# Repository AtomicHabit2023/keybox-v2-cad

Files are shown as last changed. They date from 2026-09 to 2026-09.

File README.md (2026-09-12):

# KeyBox V2 CAD

Shared design workspace for the 48-door KeyBox V2 mechanical/CAD project.

## Working model

- **ChatGPT**: project designer / design authority. Maintains requirements, parameters, design decisions, review gates, corrections, and approvals.
- **Codex**: CAD execution agent. Uses Fusion 360 through MCP to build, measure, test, and report the actual model.
- **Fusion 360**: authoritative geometric/interference environment.
- **GitHub**: shared source of truth and agent-to-agent handoff channel.
- **Owner**: product/business owner and physical-world operator; should not be used as a routine message courier between ChatGPT and Codex.

## Read these first

1. `AGENTS.md`
2. `CAD_REVIEW_PROTOCOL.md`
3. latest applicable files under `reviews/`
4. `CAD_MASTER_SPEC.md`
5. `PARAMETERS.json`
6. `DESIGN_DECISIONS.md`
7. `CAD_TASKS.md`
8. `CAD_LOG.md`

## Direct agent workflow

From CAD-002 onward, Codex works on one task branch such as `cad/CAD-002`, saves Fusion evidence, writes `handoff/CAD-002.json`, commits and pushes through the restricted **KeyBox Git Bridge MCP**, and stops at the review gate.

ChatGPT reviews the pushed branch/PR and returns one of `APPROVED`, `CHANGES_REQUIRED`, or `HUMAN_DECISION_REQUIRED` in `reviews/CAD-###_RESULT.md`.

The owner is asked only when a physical measurement, fabrication-shop fact, purchase/cost fact, installation constraint, or product/business tradeoff genuinely requires a human decision.

See `CAD_REVIEW_PROTOCOL.md` for the full contract.

## KeyBox Git Bridge MCP

`tools/keybox_git_bridge/` contains a restricted local MCP server for Git fetch/pull/branch/stage/commit/push operations. It runs in the normal Windows user context so Git can use the owner's existing SSH setup, while Codex never receives direct access to the private SSH key. Direct pushes to `main` are blocked by the bridge.

## Current CAD status

- Phase-1 parameter/reference geometry was successfully created in Fusion 360.
- The earlier Phase-2 master latch reference was geometrically inaccurate and is **superseded**.
- CAD-001 has been restored to the correct baseline: maximum complete formed door envelope `87.5 × 47.0 mm`; the planar center face is derived (restored baseline about `84.8 × 41.6 mm`).
- CAD-002 remains blocked until CAD-001's final evidence checkpoint is explicitly approved.

## Manufacturing philosophy

Design for ordinary Thai laser-cut / press-brake / welding shops, not specialized tooling. Keep the product parametric, self-jigging, low-part-count, serviceable, and inexpensive to fabricate. Critical repeated dimensions must come from named parameters, never duplicated hard-coded values.

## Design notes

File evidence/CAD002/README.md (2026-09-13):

# CAD-002 corrected U-catch review evidence

Status: READY_FOR_DESIGN_REVIEW

Controlling decision: reviews/CAD-002_RESULT.md, read from refreshed main at 1070e73 on 2026-09-13. This evidence supersedes the original CAD-002 package and its provisional spacing.

## Corrections and verification

- Plate: 20.0 x 34.5 x 1.5 mm; local X 62.5-82.5, Y 12.0-13.5, Z 7.75-42.25 mm.
- Two through-holes in the catch plate only: diameter 4.2 mm, vertical centers 25.0 mm apart (drawing tolerance +/-0.2 mm). Centers X 72.5, Z 12.5 and 37.5 mm. The approved door return was not drilled or modified.
- Two diameter 3.0 mm projecting legs: centers X 65.5 and 79.5 mm, both at Z 25.0 mm; axes parallel to Y. Horizontal center spacing 14.0 mm, outside width 17.0 mm, inside clear spacing 11.0 mm.
- Projection: 26.0 mm from plate outer face Y 13.5 to loop furthest Y 39.5 mm (drawing tolerance +/-1 mm).
- Original edge inset remains 5.0 mm from door-edge reference X 87.5 to plate edge X 82.5 mm.
- Catch occurrence transform matches the door at the original 550 mm X review offset and is grounded for static review.
- Rebuilt only the catch using six fully constrained sketches and six healthy extrusion/cut features. Functional dimensions and offsets reference named parameters.
- Door body revision is identical before and after correction: 947b7e2e-ea4f-4ad2-9d0f-8d0c880a28ae. Volume, 46 faces, 100 edges, one sheet-metal body, 10 healthy features, 87.5 x 12 x 47 mm bounds, and existing flat pattern are preserved.
- The four-body purchased-hardware reference retains simple cylindrical legs and distal bridge. Cosmetic welds and detailed bend-end refinements are outside this correction.

## Evidence

- CAD002_front.png: plate front view from the compartment side (+Y looking toward -Y), with Z vertical; shows horizontal loop orientation and both mounting holes.
- CAD002_top.png: view from +Z, showing loop projection and width.
- CAD002_isometric.png: assembled view from the compartment side.
- CAD002_MEASUREMENTS.json: fresh Fusion geometry measurements and acceptance assertions; all pass.
- KeyBox_V2_CAD002_UCatch.f3d: corrected native Fusion checkpoint.

The three images were visually inspected after export. The saved Fusion document is KeyBox_V2_CAD002_UCatch.

No provisional loop-spacing deviation remains. This is the static CAD-002 gate only. No shield, lock body, red wall, shim, hinge rod, motion study, or pattern was added. CAD-003 remains blocked pending design-authority approval.

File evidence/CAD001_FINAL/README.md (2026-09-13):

# CAD-001 Final Baseline Evidence

This package records the restored, correct CAD-001 master-door baseline for final design review.

## Controlling interpretation

- The complete formed door envelope is **87.5 x 12.0 x 47.0 mm**.
- The uninterrupted planar front region is a derived result of approximately **84.8 x 41.6 mm**.
- The formed envelope fits the **90 x 50 mm** cell pitch with nominal gaps of 2.5 mm horizontally and 3.0 mm vertically.
- All four 90-degree bends are healthy and point in the required inward/hidden-return directions.
- The sheet-metal body and flat pattern are healthy.

## Files

- `CAD001_FINAL_front.png` - front review view of the restored baseline.
- `CAD001_FINAL_top.png` - top review view of the restored baseline.
- `CAD001_FINAL_isometric.png` - isometric review view of the restored baseline.
- `CAD001_FINAL_MEASUREMENTS.json` - machine-readable geometry, feature-health, fit, and scope checks.
- `KeyBox_V2_CAD001_MasterDoor_FINAL.f3d` - saved native Fusion checkpoint of the restored baseline.

## Provenance and scope

The images, measurements, and native checkpoint are taken from the saved original CAD-001 baseline that predates and supersedes the abandoned oversized CAD-001R attempt. No CAD-001R artifact is included in this package. No Fusion geometry was modified while preparing this final review package, and CAD-002 was not started.

This checkpoint is for design review only and is not a released manufacturing blank.

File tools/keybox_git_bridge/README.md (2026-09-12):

# KeyBox Git Bridge MCP

A deliberately restricted local MCP server that lets Codex perform the Git operations needed for the KeyBox V2 CAD review loop **without giving the Codex sandbox direct access to the owner's SSH private key or unrestricted filesystem**.

The bridge runs as the normal Windows user, listens only on localhost, is hard-scoped to one repository, and exposes only a small allowlist of Git operations.

## Allowed repository

Default:

`C:\Users\wirat\Documents\Codex\keybox-v2-cad`

Override only when deliberately relocating the repo:

`KEYBOX_REPO=<absolute path>`

Default MCP endpoint:

`http://127.0.0.1:8765/mcp`

## Exposed tools

- `git_status`
- `git_log`
- `git_diff_summary`
- `git_fetch_origin`
- `git_pull_ff_only`
- `git_create_or_switch_branch`
- `git_stage`
- `git_commit`
- `git_push_head`

Safety behavior:

- no arbitrary shell command tool;
- no delete/reset/clean/rebase/force-push tool;
- `git_stage` accepts only explicit repository-relative paths;
- branch names are validated;
- `git_push_head` refuses to push `main`;
- subprocesses use `shell=False`;
- all commands run only inside the configured KeyBox repository;
- HTTP transport binds to `127.0.0.1`, not the LAN.

## One-time install

Python 3.10+ is required. The official MCP Python SDK v2 is used.

Run from a **normal Windows PowerShell**, not inside the Codex sandbox:

```powershell
cd C:\Users\wirat\Documents\Codex\keybox-v2-cad\tools\keybox_git_bridge
py -m venv .venv
.\.venv\Scripts\Activate.ps1
python -m pip install --upgrade pip
python -m pip install "mcp>=2,<3"
```

## Start the bridge

From the same normal Windows account:

```powershell
cd C:\Users\wirat\Documents\Codex\keybox-v2-cad\tools\keybox_git_bridge
.\.venv\Scripts\Activate.ps1
python server.py
```

Leave that small PowerShell window running while Codex is doing CAD work. The bridge should listen at:

`http://127.0.0.1:8765/mcp`

The server code uses MCP Streamable HTTP. The official MCP Python SDK v2 supports this transport; the server is intentionally local-only.

## Add to Codex

Add a custom HTTP MCP server named something like:

`keybox-git`

with URL:

`http://127.0.0.1:8765/mcp`

Exact UI placement can vary by Codex version. After adding it, ask Codex to list/use the `keybox-git` tools.

## First connection test

Ask Codex to call only:

`git_status`

Expected result: it reports the KeyBox repository path, current branch and status **without trying to read `.ssh` from inside the Codex sandbox**.

Then test:

1. `git_fetch_origin`
2. `git_status`

For real CAD work, create branches only when a task is released, e.g. `git_create_or_switch_branch("cad/CAD-002")`.

## Why this solves the earlier failure

Codex's normal sandbox could edit the repository but could not read the user's `C:\Users\wirat\.ssh` credential files. This bridge runs in the normal Windows user context, so Git can use the already-configured SSH/ssh-agent environment while Codex sees only narrow Git tools, never the private key itself.

## Operational rule

From CAD-002 onward Codex should use the bridge for all network Git operations and work on `cad/CAD-###` branches. Direct pushes to `main` remain blocked by the bridge.

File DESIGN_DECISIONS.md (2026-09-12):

# Design Decisions — KeyBox V2

This file records the **current approved decisions** and important superseded ideas so CAD execution does not regress to earlier concepts.

## Current approved decisions

- 48 compartments = 4 columns × 12 rows.
- Horizontal order: Col1 + SVC1 + Col2 + Col3 + SVC2 + Col4.
- 90 mm column pitch, 50 mm row pitch, 100 mm compartment depth, 40 mm service channel clear width.
- Structural sheet: 1.2 mm nominal **hot-rolled** mild steel.
- Starting slot width for tab/grid interlock: 1.30 mm = 1.20 + 0.10 mm allowance.
- Col2/Col3 use 50/50 mm half-depth egg-crate interlock through 100 mm depth.
- Col1/Col4 use separate outer-divider family.
- Shared full-height Ø4 mm hinge rod per column; 4 rods total.
- Door uses 10 mm top and bottom inward flanges with rod holes.
- Door face starting size: 87.5 × 47.0 mm.
- Latch side uses double 90° folds: 12 mm first flange + 25 mm return flange.
- U-catch is moved 5 mm inward from original door-edge reference.
- Catch sweep must be checked dynamically; V1 failed from swept-path collision.
- Blue protective shield is integrated into continuous formed sheet geometry and must have local U-catch pass-through relief/opening.
- Red service wall stops near lock rear; it is not full 100 mm deep.
- XG-07A lock requires one-piece shim between lock body and red wall.
- Prototype lock mounting: 1 round locating hole + 2 short adjustment slots.
- Two harness routes per 40 mm service channel, center kept clear.
- Control-bay UI layout: **Display → Keypad → QR**, horizontal.
- Control bay rear cover: bottom-hinged swing-down service panel; low-voltage controller electronics can mount to it.
- Moving cabinet rear structural frame: 25×25×3 mm angle iron.
- Main cabinet service opening: **90° to the left**, not 180°.
- Wall support architecture: fixed left hinge rail + bottom support rail + right support structure.
- Two Solex master locks on right side: upper-right and lower-right, preferably keyed alike.
- Bottom wall rail carries closed-position weight; master locks provide security, not primary structural support.
- Powder coat only after complete bare-steel functional dry-build passes.

## Superseded / rejected ideas

- 64-box target for this V2 cabinet — current cabinet design is 48 boxes.
- 6×8 layout — replaced by 4×12.
- Individual concealed pivot pins per door — rejected; returned to shared full-height rods.
- Separate bolt-on solenoid shield — superseded by integrated formed shield concept.
- Full-depth red service wall — rejected because it blocks rear wiring/service access.
- Full-depth blue shield to the front — rejected because it conflicts with double-fold/U-catch sweep.
- Whole service-wall front setback — rejected due security/open-gap concern.
- Four removable concrete-wall bolts as normal cabinet closure — rejected; fixed support rails restored.
- Custom vertical two-point master-lock linkage — rejected in favor of two simple Solex locks.
- 180° cabinet service swing — rejected because hinge offset becomes awkward; current requirement is 90°.
- Vertical UI stack — replaced by horizontal Display-Keypad-QR layout.
- Cold-rolled SPCC requirement — replaced by commonly available 1.2 mm hot-rolled mild steel.
- 1.4–1.5 mm tab-slot width — replaced by 1.30 mm starting slot width based on user V1 fabrication experience.
- Earlier Phase-2 Fusion master-latch reference geometry — geometrically inaccurate and must not be reused as the basis for final CAD.

## Process decision

ChatGPT remains design authority. Codex is CAD execution agent through Fusion MCP. Codex must not silently invent mechanical decisions. Every high-risk feature is built and reviewed incrementally before replication.

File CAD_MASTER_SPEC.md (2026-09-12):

# CAD Master Specification — KeyBox V2

## 1. Product goal

48-door smart apartment key cabinet intended for complete installed supply in Thailand. V2 must prove both functional reliability and local fabrication economics. The metal cabinet design is intended to be manufacturable by ordinary Thai laser-cut / press-brake / welding shops, while electronics/software remain the differentiated smart-control layer.

## 2. Frozen overall architecture

- Capacity: **48 key compartments**.
- Arrangement: **4 columns × 12 rows**.
- Horizontal sequence, left to right:
  **Col1 + Service #1 + Col2 + Col3 + Service #2 + Col4**.
- Nominal locker column pitch: **90 mm**.
- Nominal row pitch: **50 mm**.
- Compartment nominal depth: **100 mm**.
- Service-channel clear width: **40 mm** each.
- Locker matrix height: **600 mm**.
- Core internal width: **440 mm** before outer skins / finished edge geometry.
- Structural sheet: **1.2 mm nominal hot-rolled mild steel**.

Each apartment stores one normal key on a small ring/tag; usable key-space width may therefore be significantly less than 90 mm after lock/shield allocation.

## 3. Service-channel / lock architecture

Each service channel serves 24 locks: 12 from each adjacent column.

- XG-07A style 4-wire electronic locker lock.
- Lock body is inside each tenant compartment, adjacent to service channel.
- Lock is protected from tenant access by a formed shield integrated into the sheet geometry.
- Solenoid mounting screws are accessed from the protected service side.
- Lock wires exit into service channel and run upward to control bay.
- Rear access must permit replacing the lock without removing the door, horizontal divider, blue shield, or neighboring lock.
- Red service wall depth is **not 100 mm**; it stops near the rear edge of the solenoid to leave an open wire/service zone.
- Blue shield must have a laser-cut U-catch pass-through opening sized from the actual U-catch swept envelope plus clearance.

## 4. Master door geometry

Starting values:

- Visible door face width: **87.5 mm**.
- Visible door face height: **47.0 mm**.
- Door sheet: **1.2 mm**.
- Top inward hinge flange: **10 mm**.
- Bottom inward hinge flange: **10 mm**.
- Shared hinge rod: **Ø4 mm stainless steel**.
- Door hinge holes: **Ø4.6 mm starting**.
- Nylon/PTFE washer: **0.5 mm starting**.

The top and bottom flanges contain the hinge holes; one full-height rod serves all 12 doors in a column. Four columns = four shared rods.

### Latch-side folds

- First latch-side flange: **12 mm**, 90°.
- Second return flange: **25 mm**, 90°.
- U-catch plate width: **20 mm**.
- Catch is positioned **5 mm inward from the original door-edge reference**, so the 25 mm return is conceptually 20 mm catch plate + 5 mm inset.
- Final catch placement must be checked against the physical XG-07A catch and hook.

### Critical V1 lesson

The V1 cabinet failed because the U-catch could fit at the final closed position but collided with the wall during its rotating sweep. V2 must always be designed from the **full moving swept envelope**, not only open/closed static positions.

Minimum starting sweep clearance: **4 mm** around the real moving U-catch geometry where required.

## 5. Blue shield and red wall

The user-approved cross-section uses continuous formed sheet geometry, with a protected lock zone adjacent to the service channel.

- Starting clear key-space width: **65 mm**.
- Starting lock/shield zone width: **25 mm**.
- Blue protective shield is continuous vertically for a column where practical.
- Blue shield begins only behind the latch sweep zone; its exact front setback is CAD-derived from the actual catch sweep.
- Blue shield requires a local laser-cut pass-through for the U-catch.
- Red service wall is continuous where required to mount locks but stops at/near the rear of the lock, leaving rear service access into the 40 mm channel.
- No straight unauthorized tool path from tenant compartment into lock wiring/emergency-release area.

## 6. XG-07A / shim / mounting

Nominal XG-07A reference dimensions from supplied drawing:

- Body length: ~53 mm.
- Body height: ~40 mm.
- Body thickness: ~13 mm.
- Catch plate: ~20 mm × 36.5 mm.
- Catch loop projection: ~26 mm.
- Three M4 mounting holes in lock body.
- Emergency manual release and wiring are at the rear end.

A **rigid one-piece shim** is mandatory between lock body and red service wall. It accounts for catch inset plus additional alignment offset. Starting shim expectation is approximately **7–8 mm**, but final thickness must be derived from actual hook-to-catch alignment in CAD and prototype testing.

Prototype-friendly mounting pattern on red service wall:

- **1 locating round hole**.
- **2 short adjustment slots**.
- Starting round-hole diameter: **4.5 mm**.
- Starting slot width: **4.5 mm**.
- Starting slot length: **7.0 mm**.

The nominal mounting pattern must be derived from the final hook/catch geometry. Codex must not assume a guessed pattern is fabrication-ready.

## 7. Horizontal dividers / grid

Two divider families are required:

1. **Outer divider** for Col1 and Col4.
2. **Center divider** spanning Col2 + Col3.

Col2/Col3 use a true egg-crate interlock:

- Compartment depth: 100 mm.
- Horizontal divider slot: **50 mm deep** from one edge.
- Central vertical divider slot: **50 mm deep** from the opposite edge.
- Starting nominal slot width: **1.30 mm** for 1.2 mm nominal sheet.

The horizontal tenant divider stops at the blue shield and does not unnecessarily divide the vertical lock/service strip.

There are 11 internal row dividers; top and bottom structural plates provide the remaining boundaries.

## 8. Tab / slot rules

- `SHEET_T = 1.20 mm` nominal.
- `SLOT_CLEARANCE = 0.10 mm` starting.
- `SLOT_W = SHEET_T + SLOT_CLEARANCE = 1.30 mm` starting.
- All repeated slots must reference one named parameter.
- Laser-cut slots/tabs establish geometry and squareness.
- Welding only locks an already-located structure; welding must not establish pitch or alignment.
- Avoid long continuous welds on 1.2 mm sheet to reduce distortion.

## 9. Door rod support

- Four full-height Ø4 mm stainless rods.
- Rods pass through door top/bottom flange holes.
- Bottom matrix plate guides rod but should not be the sole axial support.
- Add a dedicated bottom-front hinge support rail beneath the matrix; rod projects through plate and rests/supports at the lower rail.
- Rods withdraw upward into top control bay for rare door replacement.
- Top control bay contains removable rod-retention/keeper feature.

## 10. Control compartment

- Control bay width = exact finished cabinet-body width.
- Nominal depth: **100 mm**.
- Starting height: **~165 mm**, adjust from actual UI packing.
- Horizontal front layout, left to right:
  **Display → Keypad → QR**.
- Keypad should be biased closer to display than QR because display+keypad form one workflow.
- Fixed secure front fascia; no public-side service fasteners.
- One removable internal UI carrier plate for display/keypad/QR.
- Rear service panel is bottom-hinged and swings down after the whole cabinet is opened.
- Rear panel retained at top by two repeated-service machine screws into captive/rivnut-type threads.
- Support straps keep rear service panel near ~90° open position.
- Low-voltage controller electronics may mount on the swing-down rear service panel.
- Prefer fixed mains/high-voltage and heavier PSU items in main enclosure rather than repeatedly flexing mains wires on service tray.

Reference UI hardware:

- 3.5 in ILI9488 display, non-touch preferred.
- Industrial keypad ~79.5 × 99.5 mm face.
- GM865 QR scanner.

## 11. Vertical-service-channel wiring

Each 40 mm channel has two harness routes, one along each side, leaving the center clear for tools/emergency access.

- Keep factory lock pigtail replaceable via connector.
- Place connector toward the rear open service portion, away from U-catch/hook motion.
- Starting lock service loop: **60 mm**.
- Use small laser-cut cable-tie slots rather than bulky cable duct where practical.
- Assume all four XG-07A conductors remain available until electrical bench testing proves otherwise.

## 12. Rear structural frame / wall mounting

Moving cabinet:

- Full rear perimeter frame: **25 × 25 × 3 mm angle iron**.
- Three substantial hinges on left side.
- Cabinet service swing: **90°**, left-opening.
- Hinge axis may therefore sit close to rear wall plane; exact hardware clearance still CAD-derived.

Fixed wall support:

- Left hinge rail.
- Bottom support rail carrying closed-position weight.
- Right support rail / upper support structure for alignment and security.

The cabinet should not rely on hinge cantilever load during normal closed operation.

## 13. Master service locks

Use **two Solex padlocks / master-key locks**, preferably keyed alike:

- Lower-right.
- Upper-right.

Each locks the moving 25×25×3 structural frame to the corresponding fixed support structure via aligned holes. Bottom support continues to carry cabinet weight; locks provide security, not primary structure.

Master-lock hole diameter and offsets remain hardware-derived parameters.

## 14. Materials and finish

- Main structural sheet: **1.2 mm nominal hot-rolled mild steel**.
- Main rear moving frame: **25×25×3 mm mild-steel angle**.
- Shared door hinge rods: **Ø4 mm SUS304 stainless starting choice**.
- Powder coat after all welding and bare-steel functional dry-build checks.
- Starting powder thickness target: roughly **70–90 μm**.
- Proper preparation needed for hot-rolled surface / scale / oil before coating.
- Repeated-service fasteners: machine screws into captive nuts/rivnuts; avoid self-tapping screws for repeated maintenance points.

## 15. Sheet-metal modeling rules

Global starting parameters:

- Inside bend radius: **1.5 mm**.
- K-factor: **0.42** starting only; calibrate with actual shop/bend coupon.
- Standard bend: 90° unless specified.
- Bend-relief starting width: 2.0 mm.
- Bend-relief starting depth: 3.5 mm.

Critical dimensions describe the **finished folded geometry**. Flat patterns should derive from the Fusion sheet-metal rule rather than hard-coded manual deductions.

The U-catch sweep relief is a separate functional feature and must not be conflated with generic bend relief.

## 16. Assembly / prototype sequence

1. Build locker grid in bare steel using tab/slot geometry.
2. Add control shell and rear structural frame.
3. Prove shared hinge rods fit and withdraw correctly before doors.
4. Build and prove **one master door/latch cell**.
5. Only after the master cell passes, replicate to all 48 positions.
6. Fit all doors/locks in bare steel and cycle them.
7. Fit wall-support system, 90° cabinet swing, and two right-side master locks.
8. Fit rear controller tray and front UI carrier.
9. Mock up wiring and confirm every lock remains rear-serviceable.
10. Only after all functional checks: final welds, re-check, disassemble removable hardware, powder coat, final assembly.

## 17. Master-cell acceptance gates

Before replication, the one-row master cell must prove all of the following:

- Door rotates without interference.
- 12 mm + 25 mm folds are oriented exactly as intended.
- U-catch is represented from real dimensions, not a crude bounding block.
- U-catch passes through shield opening throughout motion.
- No collision with blue shield/service-side wall through full door sweep.
- U-catch engages XG-07A hook positively.
- Shim thickness gives correct hook/catch relationship.
- 1 round + 2 slot lock mounting system provides controlled prototype adjustment.
- Emergency release remains accessible from service side.
- Lock and shim can be removed/reinstalled from rear without removing door/divider/shield/neighbouring lock.
- Tenant cannot directly access lock mounting screws, wiring, or emergency release.

## 18. CAD governance

- All repeated dimensions are named user parameters.
- Do not hard-code the same functional dimension in multiple sketches/features.
- Do not pattern 48 copies until the master cell is explicitly approved.
- Do not fabricate from provisional reference solids.
- Do not silently resolve contradictions. Stop and document them for design review.
- Maintain a running execution log in `CAD_LOG.md`.

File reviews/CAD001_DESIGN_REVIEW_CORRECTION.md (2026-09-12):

# CAD-001 Design Review Correction — Envelope vs planar face

## Status
The previous review instruction that required an uninterrupted planar front face of **87.5 × 47.0 mm** is **rescinded**.

## Reason
CAD-001R demonstrated that keeping the planar face at 87.5 × 47.0 mm produces a formed overall envelope of about **90.2 × 52.4 mm**. That exceeds the 90 × 50 mm cell pitch and therefore violates the required inter-door clearance.

The original CAD-001 interpretation was physically correct for the cabinet layout:

- **DOOR_ENVELOPE_W = 87.5 mm**
- **DOOR_ENVELOPE_H = 47.0 mm**

These are the maximum formed front-projection dimensions of the complete bent door, not the uninterrupted planar center panel.

With R1.5 mm and 1.2 mm sheet, the corresponding uninterrupted planar region was measured at about **84.8 × 41.6 mm**. That is acceptable; it is a derived consequence of the bend radii and is not itself the controlling cabinet-fit dimension.

## Required action
1. Stop CAD-001R before committing it as an approved replacement.
2. Restore/retain the original CAD-001 formed-envelope geometry where the complete door fits within 87.5 × 47.0 mm.
3. Keep the 10 mm top/bottom inward hinge flanges, 12 mm first latch flange, 25 mm return, R1.5 mm, K=0.42 starting rule, and the existing healthy sheet-metal topology.
4. Treat the planar front-panel size as a **derived** value, not a fixed requirement.
5. Do not start CAD-002 until this correction is acknowledged and the CAD-001 checkpoint is confirmed as the active baseline.

## Parameter naming correction
To avoid recurrence, use these meanings going forward:

- `DOOR_ENVELOPE_W = 87.5 mm`
- `DOOR_ENVELOPE_H = 47.0 mm`
- `DOOR_PLANAR_W = derived`
- `DOOR_PLANAR_H = derived`

The controlling requirement for cabinet fit is the **formed overall envelope** because the 90 × 50 mm cell pitch must retain the intended nominal gaps.

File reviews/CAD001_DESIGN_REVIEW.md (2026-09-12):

# CAD-001 Design Review

**Review status:** CHANGES REQUIRED  
**Design authority:** ChatGPT / project-design conversation  
**Reviewed checkpoint:** `93bb356aac7aac63e48f8a53af0fcd691be8e168`  
**CAD-002:** BLOCKED until CAD-001R is re-reviewed and approved.

## What is accepted from the checkpoint

The following parts of CAD-001 are accepted as the correct direction and should be preserved unless the required correction forces a rebuild:

- one true Fusion sheet-metal body;
- 1.2 mm hot-rolled-steel design thickness;
- starting sheet-metal rule R1.5 mm / K-factor 0.42;
- 10 mm top inward hinge flange;
- 10 mm bottom inward hinge flange;
- 12 mm first latch-side inward flange;
- 25 mm second latch-side return;
- all four bends at 90 degrees and directed inward toward the tenant compartment;
- current corner relief is acceptable as a prototype starting point, subject to later fabrication calibration;
- flat pattern generation is healthy;
- no U-catch, shield, lock, shim, hinge rod, or 48-copy pattern was added before the stop gate.

## Required correction

The checkpoint interpreted `DOOR_FACE_W = 87.5 mm` and `DOOR_FACE_H = 47.0 mm` as the **complete formed front projection including bend zones**. That is not the approved design intent.

**Approved definition:**

`DOOR_FACE_W = 87.5 mm` and `DOOR_FACE_H = 47.0 mm` are the dimensions of the **flat planar visible front face between the bend tangency/bend-start lines**.

The current checkpoint reports the largest uninterrupted planar front region as only **84.8 × 41.6 mm**, so CAD-001 does not yet satisfy the approved door-face requirement.

## CAD-001R instruction

Revise only the master door/folds geometry so that:

1. the planar visible front face measures **87.5 mm wide × 47.0 mm high** between the bend-start/tangency boundaries;
2. the 10 mm top and bottom flanges remain inward;
3. the 12 mm first latch flange remains inward;
4. the 25 mm second return remains the hidden return that will later carry the U-catch;
5. the body remains valid sheet metal and still produces a valid flat pattern;
6. no bend or relief self-intersects;
7. after correcting the planar face, measure the **actual formed overall envelope** and report it separately;
8. compare that formed envelope against the **90 mm × 50 mm cell pitch**. If any formed portion would interfere with the neighboring row/column or violate the intended door gaps, **STOP and report the conflict; do not change the approved 87.5 × 47.0 planar-face dimensions without design-authority approval**;
9. do not add U-catch, blue shield, red wall, XG-07A, shim, hinge rod, or any patterned copies.

## Dimension terminology to use from now on

- **Door face:** flat planar front face between bend tangencies; target 87.5 × 47.0 mm.
- **Formed envelope:** maximum outside bounds of the complete folded door; this is a reported/check dimension, not the definition of `DOOR_FACE_W/H`.
- **Cell pitch:** 90 × 50 mm structural pitch; formed envelope must be checked against it.

## Review gate for CAD-001R

Return for review with:

- front / top / isometric screenshots;
- exact planar-face measurement;
- exact formed-envelope measurement;
- sheet-metal feature health;
- flat-pattern health;
- explicit clearance/interference statement relative to the 90 × 50 mm cell pitch;
- updated `.f3d` checkpoint and machine-readable measurement file.

Do **not** start CAD-002 until this review file is superseded by an explicit `CAD-001 APPROVED` decision.

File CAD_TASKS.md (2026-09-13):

# CAD Tasks — KeyBox V2

## CAD-001 — Rebuild master door cell, folds only

**Status:** APPROVED

### Approved baseline

- Reference cell: 90 × 50 × 100 mm.
- Complete formed door envelope: **87.5 × 12.0 × 47.0 mm**.
- Derived uninterrupted planar front region: approximately **84.8 × 41.6 mm**.
- Door sheet: 1.2 mm.
- Top inward hinge flange: 10 mm.
- Bottom inward hinge flange: 10 mm.
- First latch-side flange: 12 mm at 90°.
- Second latch-side return flange: 25 mm at 90°.
- Starting sheet-metal rule: 1.2 mm thickness, 1.5 mm inside bend radius, K-factor 0.42.
- Four required bends healthy; flat pattern healthy.

`87.5 × 47.0 mm` remains the **maximum complete formed door envelope**, not the uninterrupted planar center face.

See `reviews/CAD-001_RESULT.md` for the controlling approval.

---

## CAD-002 — Real U-catch on approved door

**Status:** APPROVED

### Approved geometry

- Preserve the approved CAD-001 sheet-metal door unchanged.
- Catch plate: **20.0 × 34.5 × 1.5 mm**.
- Two catch mounting holes: **Ø4.2 mm**, **25.0 ±0.2 mm** vertical center-to-center.
- U-loop rod diameter: **3.0 mm**.
- Two projecting U-loop legs arranged **horizontally left-right in plate front view**.
- Owner-measured rod outside-to-outside width: **17.0 mm**, giving **14.0 mm center-to-center** and **11.0 mm inside clear spacing**.
- Catch loop projection: **26 ±1 mm** from the plate.
- Catch mounted on the 25 mm hidden return with the approved **5.0 mm inward edge inset**.
- Approved door remains unchanged and healthy.

See `reviews/CAD-002_RESULT.md` for the controlling approval.

---

## CAD-003 — Blue shield + true U-catch sweep

**Status:** CHANGES REQUIRED / L-SHIELD REBUILD RELEASED — see `reviews/CAD-003_RESULT.md` and `DESIGN_ERRATA.md` E-002

### Frozen hinge axis

- `HINGE_AXIS_EDGE_OFFSET = 5.0 mm` from the hinge-side door edge.
- `HINGE_AXIS_FRONT_OFFSET = 5.0 mm` behind the front-face plane.
- Axis direction = Z.
- Ø4.6 mm door guide holes centered on this axis for the Ø4.0 mm shared hinge rod reference.

### Controlling shield form

- Tenant key-space width: **65 mm**.
- Lock/shield-zone width: **25 mm**.
- Blue shield is a formed **L-section**, not a small frame.
- Side partition: constant-X Y-Z sheet at nominal **X = 65 mm**, running rearward from a CAD-derived front setback toward the compartment rear.
- Front return: short constant-Y X-Z face at the side partition's leading edge, turning toward the service-channel side across the **25 mm lock zone**.
- U-catch passage: local **horizontal slot/notch in the front return**, sized from the real moving U-catch envelope plus at least **4 mm** clearance.
- `BLUE_SHIELD_FRONT_SETBACK` is the Y position of the front return / leading bend.
- The side partition remains continuous/solid except for only minimum proven transition relief.
- Do **not** use the rejected four-web rectangular frame or the superseded full-width constant-Y wall / 119 mm relief.

### Corrected scope

- Preserve approved CAD-001 door and CAD-002 U-catch unchanged.
- Keep the frozen 5 mm / 5 mm hinge axis.
- Rebuild the CAD-003 shield reference as one lightweight 1.2 mm L-shaped formed sheet segment for the master row:
  - side leg at X=65 mm;
  - side leg extends from `BLUE_SHIELD_FRONT_SETBACK` rearward toward Y=100 mm;
  - front return at the leading edge spans nominally X=65..90 mm.
- Model the U-catch slot/notch in the front return, not as a freestanding frame around the catch.
- Evaluate motion at 0°, 15°, 30°, 45°, 60°, 75°, and 90°.
- Derive both the front setback and the smallest practical front-return slot/notch from the moving catch envelope.
- Measure clearance to slot/notch edges and any nearby side-partition/bend metal.
- Minimum required moving clearance = **4.0 mm**; review target >=4.5 mm where practical.
- Keep maximum protective metal and avoid a straight tenant tool path toward wiring/emergency-release areas.

### Do not build yet

- XG-07A lock body.
- Shim.
- Red service wall.
- Final/full hinge hardware beyond the lightweight axis/reference needed for the corrected motion study.
- Patterned rows or columns.

### Stop gate / evidence

Correct only CAD-003. Save a new Fusion checkpoint; provide an isolated clear view of the full L-shaped shield segment plus front/top/isometric and 0°/15°/30°/45°/60°/75°/90° motion evidence; report front setback, front-return span, slot/notch X/Z extents, governing edge/corner, closest angle, and minimum clearance; update `CAD_LOG.md`; update `handoff/CAD-003.json` with `READY_FOR_DESIGN_REVIEW`; push branch `cad/CAD-003`; stop for design-authority review.

---

## CAD-004 — XG-07A + shim + red wall

**Status:** BLOCKED

Planned scope: build actual lock reference from drawing/measurements, derive shim thickness from hook/catch alignment, add red wall, and implement 1 round locating hole + 2 short adjustment slots.

---

## CAD-005 — Master-cell serviceability validation

**Status:** BLOCKED

Planned scope: prove rear removal/reinstallation of lock+shim, emergency-release access, wiring clearance, tenant anti-tamper separation, and zero motion interference.

---

## CAD-006 — Replicate to grid and structural architecture

**Status:** BLOCKED until master cell approved

Planned scope: only after CAD-001 through CAD-005 pass, pattern approved geometry into 4×12 structure, create outer/center divider families, service channels, shared rods, control bay, rear structural frame, wall supports, and master-lock geometry.

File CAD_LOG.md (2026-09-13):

# CAD Execution / Review Log — KeyBox V2

## 2026-09-12 — Workspace initialized

- GitHub repository established as shared design/CAD handoff channel.
- ChatGPT designated project designer / design authority.
- Codex designated CAD execution agent through Fusion MCP.
- Fusion 360 remains authoritative geometric/interference environment.

### Existing Fusion status

- Phase-1 parametric reference model successfully created and user parameters verified in Fusion.
- Earlier Phase-2 master latch cell ran technically but was visually/geometrically inaccurate.
- That earlier Phase-2 cell is **superseded and must not be used as the basis of final CAD**.

### Current approved next action

Run **CAD-001** from `CAD_TASKS.md`: rebuild only the master cell + actual sheet-metal door + top/bottom hinge flanges + 12 mm first latch fold + 25 mm return fold.

Stop after those folds are measured and visually verified. Do not add U-catch or lock until design-authority review.

### Known validation priorities

- Correct coordinate/orientation mapping.
- Real sheet-metal bends rather than crude extruded blocks.
- No corner self-intersection.
- Finished door face remains 87.5 × 47.0 mm.
- All repeated dimensions driven from named parameters.

## 2026-09-12 — CAD-001 folds completed; awaiting design review

- Connected Codex to the Autodesk Fusion MCP endpoint at `http://127.0.0.1:27182/mcp`.
- Active Fusion document: `KeyBox_V2_Phase1_Reference`.
- Preserved the superseded `01_MASTER_LATCH_CELL` geometry unchanged and hidden for review.
- Created a separate `CAD001_REFERENCE_CELL` envelope at the `MASTER_CELL_SHIFT_X = 550 mm` review offset.
- Created `02_CAD001_MASTER_DOOR_FOLDS` as a true sheet-metal component.
- Created sheet-metal rule `KEYBOX_V2_CAD001_1P2MM (Convert)` with:
  - thickness: 1.2 mm;
  - inside bend radius: 1.5 mm;
  - K-factor: 0.42;
  - relief width: 2.0 mm;
  - relief depth: 3.5 mm.
- Created four healthy 90-degree bend features:
  - `BEND_TOP_INWARD_90` — 10 mm top hinge flange;
  - `BEND_BOTTOM_INWARD_90` — 10 mm bottom hinge flange;
  - `BEND_LATCH_FIRST_90` — 12 mm first latch-side flange;
  - `BEND_LATCH_RETURN_90` — 25 mm hidden return.
- Final formed envelope measured 87.5 mm wide × 12.0 mm deep × 47.0 mm high, with local bounds X = 0.0–87.5 mm, Y = 0.0–12.0 mm, and Z = 1.5–48.5 mm inside the 90 × 50 × 100 mm reference cell.
- The 87.5 × 47.0 mm door-face requirement was interpreted as the finished front projection including the bend zones. The largest uninterrupted planar region between bend tangencies measures 84.8 × 41.6 mm. This interpretation requires design-authority confirmation before CAD-002.
- The top, bottom, and latch-side flanges all project inward toward positive compartment depth.
- Both latch-side intersections use a 3.5 mm boundary cutback, with the rule supplying 2.0 mm × 3.5 mm bend relief. Visual inspection found no impossible corner overlap.
- Sheet-metal validation passed: one valid sheet-metal body, four healthy bend features, eight cylindrical bend faces, and a successfully generated flat pattern.
- Flat-pattern bounding size measured 119.995752 × 62.495752 × 1.2 mm. This is review evidence only, not a released manufacturing blank.
- Review images:
  - `evidence/CAD001/CAD001_front.png`
  - `evidence/CAD001/CAD001_top.png`
  - `evidence/CAD001/CAD001_isometric.png`
- No U-catch, shield, service wall, lock, shim, hinge rod, or patterned copies were added.
- Stop gate reached. CAD-002 remains blocked pending design-authority approval.
- Assumptions used for CAD-001:
  - component local +Y is inward toward the tenant compartment;
  - the door is vertically centered in the 50 mm reference cell, leaving 1.5 mm nominal clearance above and below the 47 mm formed projection;
  - the 12 mm and 25 mm latch dimensions are formed-envelope distances from the original door-edge reference;
  - the initial corner treatment uses the specified 3.5 mm boundary cutback and the rule's 2.0 mm relief width; final shop-specific relief shape remains subject to bend-coupon and fabrication review;
  - the Fusion Join By Bend preview API is acceptable for this checkpoint because it produced four healthy parametric bend features and a valid flat pattern.
- Saved the active Fusion document as `KeyBox_V2_CAD001_MasterDoor` in the `KeyBox System` Fusion folder. Saved state was verified with `isModified = false`.
- Exported the native Fusion archive checkpoint to `evidence/CAD001/KeyBox_V2_CAD001_MasterDoor.f3d`.
- Exact machine-readable measurements are stored in `evidence/CAD001/CAD001_MEASUREMENTS.json`; execution and review notes are stored in `evidence/CAD001/README.md`.

## 2026-09-13 — CAD-001 final baseline restored; ready for design review

- A later CAD-001R attempt incorrectly forced the uninterrupted planar face to 87.5 x 47.0 mm, producing an oversized formed envelope of approximately 90.2 x 52.4 mm. That attempt was abandoned and is not final evidence.
- Restored the original, physically correct CAD-001 baseline in which 87.5 x 47.0 mm controls the complete formed front-plane envelope.
- Confirmed the restored formed envelope as 87.5 mm wide x 12.0 mm deep x 47.0 mm high.
- Confirmed the derived uninterrupted planar region as approximately 84.8 x 41.6 mm.
- Retained four healthy inward 90-degree bends, a valid sheet-metal body, and a healthy flat pattern.
- Confirmed fit within the 90 x 50 mm cell pitch, leaving 2.5 mm nominal horizontal gap and 3.0 mm nominal vertical gap.
- Created the final review package at `evidence/CAD001_FINAL/`, including front, top, and isometric views; machine-readable measurements; notes; and the saved native `.f3d` checkpoint.
- No Fusion geometry was modified while preparing the final evidence package.
- CAD-002 remains blocked and was not started.

## 2026-09-13 — CAD-002 real U-catch completed; ready for design review

- Synchronized `main` after `reviews/CAD-001_RESULT.md` approved CAD-001 and explicitly released CAD-002.
- Created task branch `cad/CAD-002` and saved a separate Fusion checkpoint as `KeyBox_V2_CAD002_UCatch`, preserving the approved CAD-001 document and door geometry.
- Preserved `02_CAD001_MASTER_DOOR_FOLDS` as one unchanged sheet-metal body with 10 healthy features and its flat pattern present.
- Added `03_CAD002_XG07A_UCATCH` as a separate grounded component at the same 550 mm occurrence transform as the approved door.
- Modeled the catch as a 20.0 × 36.5 × 1.5 mm plate plus a round 3.0 mm rod U loop made from two projecting legs and a distal bridge, rather than the superseded crude bounding block.
- Mounted the plate on the outer face of the 25 mm hidden return. Local plate bounds are X = 62.5–82.5 mm, Y = 12.0–13.5 mm, and Z = 6.75–43.25 mm.
- Verified the approved 5.0 mm inward inset from the original door-edge reference at X = 87.5 mm to the plate edge at X = 82.5 mm.
- Verified the loop's furthest point projects 26.0 mm from the plate outer face, from Y = 13.5 mm to Y = 39.5 mm.
- Added named parameter `UCATCH_LOOP_LEG_SPACING = 12 mm` as an explicitly provisional dimension because the repository does not state the physical catch's leg-center spacing; design-authority confirmation is requested before fabrication use.
- Generated fresh front, top, and isometric screenshots, machine-readable measurements, notes, and a native `.f3d` checkpoint under `evidence/CAD002/`.
- Did not add a blue shield, XG-07A lock body, red service wall, shim, hinge rod, or patterned copies.
- Did not perform or claim swept-motion approval; that work remains CAD-003.
- Stop gate reached with `handoff/CAD-002.json` set to `READY_FOR_DESIGN_REVIEW`.

## 2026-09-13 - CAD-002 controlling corrections completed; ready for design review

- Switched to main and fast-forward pulled through the KeyBox Git Bridge, reading the refreshed AGENTS.md, CAD_TASKS.md, and controlling reviews/CAD-002_RESULT.md at 1070e73 before returning to cad/CAD-002.
- Applied only the required catch corrections: plate height 34.5 mm; horizontal diameter 3 mm legs at 14 mm centers; two diameter 4.2 mm catch mounting holes at 25 mm vertical centers.
- Verified 17 mm rod outside width, 11 mm inside clearance, 26 mm plate-to-loop projection, and unchanged 5 mm inward inset. The owner-confirmed spacing replaces the provisional 12 mm value.
- Rebuilt only the catch as six fully constrained sketches and six healthy extrusion/cut features referencing named parameters. Preserved the lightweight four-body reference representation.
- Verified the catch occurrence matches the door at the 550 mm review offset and is grounded. Confirmed the CAD-001 body revision, volume, topology, bounds, 10 healthy features, and existing flat pattern are unchanged.
- Saved the corrected Fusion document, exported the native archive, regenerated machine-readable measurements and front/top/isometric images, and visually inspected all three views.
- Updated evidence/CAD002/README.md and handoff/CAD-002.json to READY_FOR_DESIGN_REVIEW with no provisional spacing deviation or outstanding measurement question.
- Stopped at the CAD-002 review gate. CAD-003 and all subsequent geometry remain blocked pending authority approval.

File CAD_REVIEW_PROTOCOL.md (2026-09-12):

# CAD Review Protocol — ChatGPT ↔ Codex

Purpose: remove the owner from routine message relaying while preserving explicit design-control gates.

## Roles

**Codex / Fusion executor** builds and measures the CAD. It does not invent design requirements.

**ChatGPT / design authority** reviews evidence against the specification, issues corrections, approves gates, and releases the next task.

**Owner** is involved only for physical-world facts or real product/business choices that cannot be resolved from the repository and Fusion model.

## Task branches

Use one branch per CAD stage:

`cad/CAD-001`, `cad/CAD-002`, `cad/CAD-003`, ...

Do not mix two CAD stages in one branch unless the design authority explicitly says so.

## Review handoff file

At each stop gate, Codex writes:

`handoff/CAD-###.json`

Recommended schema:

```json
{
  "task": "CAD-002",
  "status": "READY_FOR_DESIGN_REVIEW",
  "branch": "cad/CAD-002",
  "fusion_document": "KeyBox_V2_CAD002_UCatch",
  "head_sha": "<filled after commit if practical>",
  "summary": "What was built",
  "evidence": [
    "evidence/CAD002/front.png",
    "evidence/CAD002/top.png",
    "evidence/CAD002/isometric.png",
    "evidence/CAD002/MEASUREMENTS.json"
  ],
  "checks": {
    "sheet_metal_health": "PASS",
    "interference": "PASS/FAIL/NOT_APPLICABLE",
    "flat_pattern": "PASS/FAIL/NOT_APPLICABLE"
  },
  "deviations": [],
  "questions_for_design_authority": []
}
```

After writing the handoff, Codex commits and pushes the task branch using the KeyBox Git Bridge MCP and stops modifying Fusion.

## Pull-request review gate

A review PR should be titled:

`[CAD-###] <short task name>`

Base branch: `main`

Head branch: `cad/CAD-###`

The PR is the design-review container. It must include the Fusion checkpoint where practical, screenshots, machine-readable measurements, updated `CAD_LOG.md`, and the handoff JSON.

## Design-authority response

The design authority reviews the branch/PR against the current source of truth and writes:

`reviews/CAD-###_RESULT.md`

The first non-heading line must be one of:

`STATUS: APPROVED`

`STATUS: CHANGES_REQUIRED`

`STATUS: HUMAN_DECISION_REQUIRED`

### APPROVED

- The gate is accepted.
- The design authority may merge the PR.
- The next CAD task may be released/unblocked.

### CHANGES_REQUIRED

- The result file must state exact corrections and acceptance checks.
- Codex modifies only the current task branch, regenerates evidence, pushes, and returns to the review gate.

### HUMAN_DECISION_REQUIRED

- The result file states the smallest concrete question that needs the owner.
- Codex and ChatGPT pause only the affected decision; unrelated approved work should not be reopened.

## Source-of-truth precedence

For a given task, use this order:

1. latest `reviews/CAD-###_CORRECTION.md` or `reviews/CAD-###_RESULT.md` explicitly marked controlling;
2. `DESIGN_ERRATA.md`;
3. `CAD_MASTER_SPEC.md`;
4. `PARAMETERS.json`;
5. `DESIGN_DECISIONS.md`;
6. `CAD_TASKS.md`;
7. `CAD_LOG.md` and evidence notes.

If a lower-priority document conflicts with a higher-priority one, log it and follow the higher-priority instruction.

## Current CAD-001 migration note

CAD-001 began before this branch/PR protocol existed. Finish its corrected baseline and evidence checkpoint without redoing healthy geometry. From **CAD-002 onward**, use this protocol by default.

## No-courier principle

The owner should not have to copy routine review messages between agents. Codex communicates through task branches/handoff files; ChatGPT communicates through PR reviews and `reviews/CAD-###_RESULT.md`. The owner is reserved for real-world facts and decisions.

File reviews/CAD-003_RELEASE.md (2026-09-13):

# CAD-003 Design Authority Release

STATUS: READY / RELEASED

## Purpose

Validate the real moving path of the already-approved CAD-001 door + CAD-002 U-catch and derive the minimum blue-shield front relief that cannot repeat the V1 collision failure.

## Preserve unchanged

- CAD-001 formed door baseline.
- CAD-002 U-catch geometry and placement.
- 20.0 x 34.5 x 1.5 mm catch plate.
- 2 x Ø4.2 mounting holes at 25.0 mm vertical centers.
- Horizontal Ø3.0 loop legs at 14.0 mm centers (17.0 mm outside width, 11.0 mm clear inside).
- 26 mm nominal loop projection.
- 5.0 mm catch edge inset.

## Token-efficient CAD procedure

1. Synchronize refreshed `main`, then create/switch to `cad/CAD-003`.
2. Save a new Fusion checkpoint before changing geometry.
3. Use only a lightweight construction hinge axis / reference needed to rotate the approved door. Do not build the final full-height hinge system in this task.
4. Keep the blue shield lightweight and parametric: only the front/adjacent geometry required to evaluate tenant protection and U-catch passage. Do not add cosmetic details, tabs, fasteners, or downstream lock hardware yet.
5. Evaluate the door/U-catch motion from closed to 90 degrees open. At minimum record interference/clearance at 0, 15, 30, 45, 60, 75, and 90 degrees. Use a true swept-body/envelope method if Fusion can generate it reliably without damaging the approved geometry; otherwise use the sampled-angle union/envelope conservatively and state the method.
6. Derive the blue-shield front opening/relief from the moving U-catch envelope plus `CATCH_SWEEP_CLEAR = 4.0 mm` minimum safety allowance. The shield must not be sized only from the static closed position.
7. Report the closest moving approach, its door angle, measured clearance, relief/opening dimensions, and the reference hinge-axis offsets used for the analysis.
8. If the required 4 mm moving clearance cannot be achieved without a major change to approved door/catch geometry, stop and return `HUMAN_DECISION_REQUIRED`; do not redesign CAD-001 or CAD-002 silently.

## Do not build

- XG-07A lock body.
- Shim.
- Red service wall.
- Final/full hinge hardware.
- 48-door pattern or other rows/columns.

## Stop gate

Save the Fusion checkpoint; generate front/top/isometric evidence plus representative sweep-angle views and machine-readable clearance measurements; update `CAD_LOG.md`; create `handoff/CAD-003.json` with `READY_FOR_DESIGN_REVIEW`; push `cad/CAD-003`; stop.

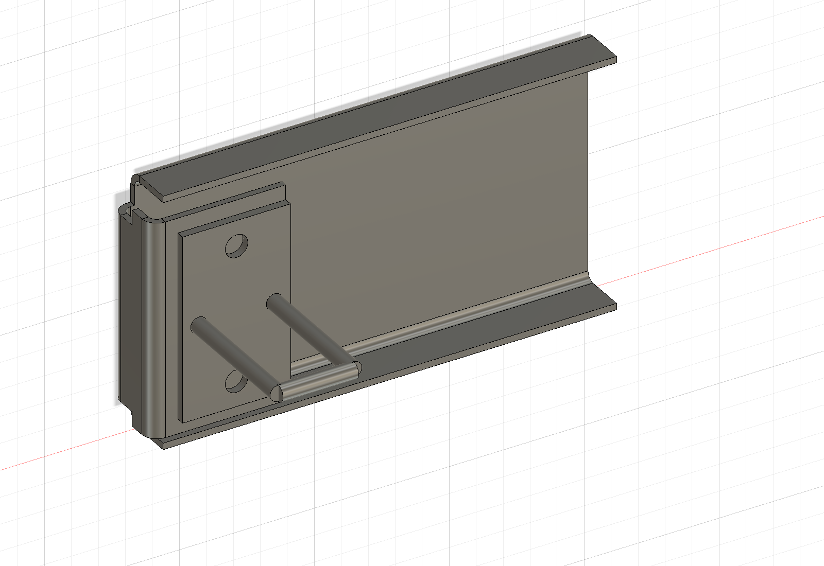
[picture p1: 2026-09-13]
evidence/CAD002/CAD002_isometric.png

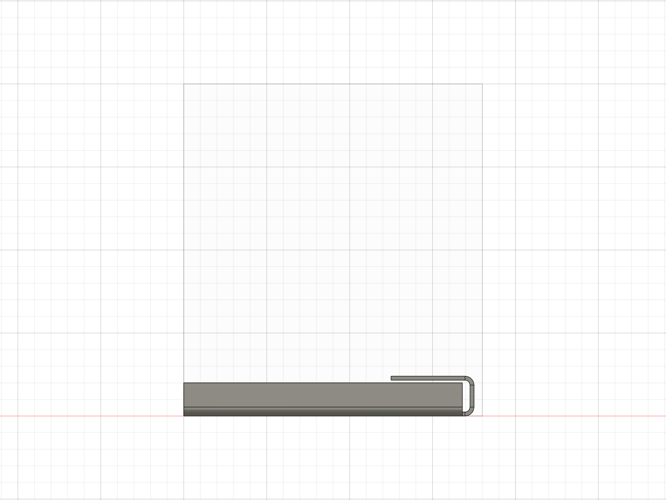
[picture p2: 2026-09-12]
evidence/CAD001_FINAL/CAD001_FINAL_front.png

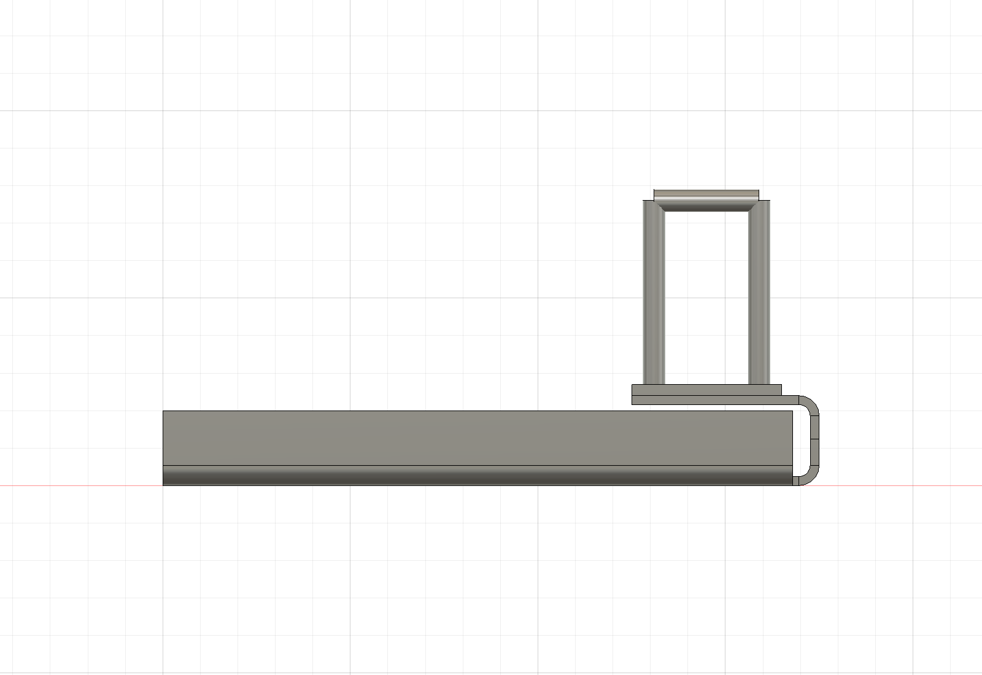
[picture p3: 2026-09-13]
evidence/CAD002/CAD002_top.png

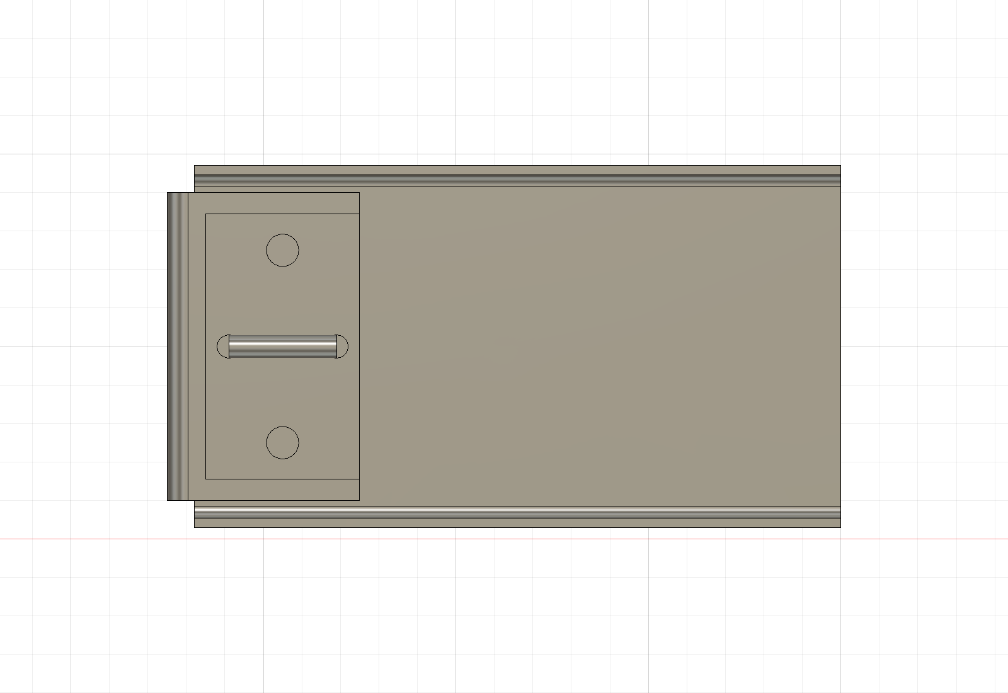
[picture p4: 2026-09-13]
evidence/CAD002/CAD002_front.png

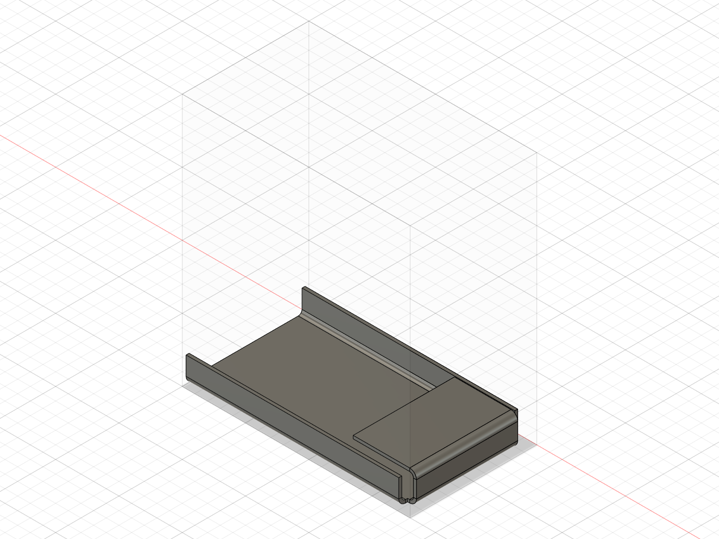
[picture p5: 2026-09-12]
evidence/CAD001_FINAL/CAD001_FINAL_isometric.png

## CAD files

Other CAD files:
evidence/CAD001_FINAL/KeyBox_V2_CAD001_MasterDoor_FINAL.f3d
evidence/CAD002/KeyBox_V2_CAD002_UCatch.f3d

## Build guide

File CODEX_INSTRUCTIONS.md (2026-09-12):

# Codex Instructions — KeyBox V2 CAD Executor

You are the CAD execution agent for the KeyBox V2 project. ChatGPT is the project designer / design authority. Fusion 360 through MCP is the geometric execution environment.

## Before modifying Fusion

Read, in this order:

1. `AGENTS.md`
2. `CAD_REVIEW_PROTOCOL.md`
3. latest applicable task review/correction under `reviews/`
4. `CAD_MASTER_SPEC.md`
5. `PARAMETERS.json`
6. `DESIGN_DECISIONS.md`
7. `CAD_TASKS.md`
8. latest entries in `CAD_LOG.md`

Treat those files as the current requirements. If they conflict, follow the precedence in `CAD_REVIEW_PROTOCOL.md`. Never silently choose between contradictory requirements.

## Core rules

- Do not redesign the product unless the task explicitly asks for a design proposal.
- Do not substitute general CAD best practice for explicit project requirements.
- Do not hard-code repeated functional dimensions; use Fusion user parameters with the same canonical names as `PARAMETERS.json` wherever practical.
- Do not pattern 48 doors/locks before the master cell is approved.
- Do not build fabrication geometry from the superseded inaccurate Phase-2 master-latch solids.
- Use real sheet-metal features for critical folded parts wherever the MCP/API supports them.
- For provisional geometry, name it clearly with `REF_`, `PROVISIONAL_`, or similar.
- Never call geometry “approved” merely because Fusion accepted the operation.
- The controlling CAD-001 door rule is: **87.5 × 47.0 mm maximum complete formed envelope**. The uninterrupted planar center face is derived.

## Task-branch workflow

From CAD-002 onward, use a task branch named `cad/CAD-###`.

At the start of a task:

1. synchronize `main` through the **KeyBox Git Bridge MCP**;
2. create/switch to `cad/CAD-###` through the bridge;
3. build only the scope released in `CAD_TASKS.md` and the latest review result.

At every task gate:

- save the Fusion document;
- preserve/export a native Fusion checkpoint where practical;
- record exact parameters and measurements;
- capture front/top/isometric views where useful;
- report interference and flat-pattern health where applicable;
- update `CAD_LOG.md`;
- create/update `handoff/CAD-###.json` with `READY_FOR_DESIGN_REVIEW`;
- stage/commit the intended review files;
- push the task branch using the **KeyBox Git Bridge MCP**;
- stop CAD modification while awaiting the design-authority response.

Do not perform network Git from the normal Codex sandbox. Do not read/copy/print the owner’s SSH private key. Use only the restricted bridge for fetch/pull/push.

## Review response behavior

Look for `reviews/CAD-###_RESULT.md` or a controlling correction for the current task.

- `STATUS: APPROVED` → the gate is accepted; continue only to the next released task.
- `STATUS: CHANGES_REQUIRED` → implement only the requested corrections, regenerate evidence, push, and stop again.
- `STATUS: HUMAN_DECISION_REQUIRED` → pause the affected decision and state the smallest concrete physical/business question required from the owner.

Do not ask the owner to relay routine messages between Codex and ChatGPT.

## CAD-001 behavior

CAD-001 predates the new branch workflow. Preserve the restored healthy baseline:

- one 90 × 50 × 100 mm reference cell;
- one actual 1.2 mm sheet-metal door;
- maximum complete formed envelope 87.5 × 47.0 mm;
- 10 mm top and bottom inward hinge flanges;
- 12 mm first latch-side flange;
- 25 mm second return flange;
- derived planar center face reported separately.

Do **not** add U-catch, blue shield, red wall, shim, or XG-07A until CAD-001 is explicitly approved.

## Source-of-truth policy

If Fusion and GitHub disagree, do not silently alter one to match the other. Document the discrepancy and wait for design-authority instruction.

## Safety / serviceability priority

The product must keep tenant-accessible key space separated from lock screws, wiring, emergency release, and service channel. Rear servicing and lock replacement must remain possible without destructive disassembly.

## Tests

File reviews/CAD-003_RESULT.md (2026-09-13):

# CAD-003 Design Authority Result

STATUS: CHANGES_REQUIRED

## Decision

Owner visual review of the newest Fusion checkpoint confirms CAD-003 is **still physically wrong**.

The raw shield now sits near the master cell, but the geometry orientation is incorrect:

- the supposed 25 mm front return is visibly a **horizontal shelf/plate**;
- the side partition visibly extends far beyond the one-row height envelope;
- therefore the current body is not the agreed protective L-shield.

The correct shield is an L **in TOP/plan view**, made from two vertical faces. No slot or sweep work is authorized yet.

## Frozen geometry — do not change

- CAD-001 approved door.
- CAD-002 approved U-catch.
- 90 × 50 × 100 mm master-cell physical envelope.
- 65 mm tenant key space / 25 mm lock-zone allocation.
- 1.2 mm shield thickness.
- 5 mm / 5 mm frozen hinge axis.

## Required correction — vertical L placement only

1. Read `DESIGN_ERRATA.md` E-002 through **E-005**.
2. Hide/suppress the current incorrect CAD-003 raw shield. Preserve CAD-001/CAD-002.
3. Do not use sheet-metal bend tools for this next checkpoint if they risk another orientation error. Two simple 1.2 mm solid reference slabs are acceptable.
4. Build the **side partition as a vertical slab**:
   - located 25 mm inward from the actual service-side cell face;
   - bounded vertically between the actual bottom and top row faces (about 50 mm high);
   - extending in depth from a provisional front setback toward the actual rear face (never beyond the 100 mm cell depth).
5. Build the **front return as a second vertical slab**:
   - at the side partition's front leading edge;
   - extending from that partition toward the actual service-side face for about 25 mm;
   - bounded by the exact same bottom and top row faces (about 50 mm high).
6. The two slabs meet along a **vertical corner/bend line**. They must form an `L` when viewed from TOP.
7. The front return must **not** be horizontal. No shield body may rise above or hang below the 50 mm row envelope.
8. Do not cut the U-catch slot. Do not run any sweep. Do not push `READY_FOR_DESIGN_REVIEW`.
9. Show three placement screenshots only:
   - TOP view: obvious L footprint inside the 90 × 100 plan envelope;
   - FRONT view: front return is a vertical ~25 mm wide × ~50 mm high panel;
   - combined isometric: reference cell + approved door + approved U-catch + raw vertical L-shield.
10. Stop for owner/design-authority visual approval.
11. Do not start CAD-004.

## Current acceptance gate

The next checkpoint passes only if:

- both shield legs are vertical;
- their common corner line is vertical;
- TOP view clearly shows an L shape;
- both legs stay between the same 50 mm top/bottom row faces;
- side partition stays within the 100 mm depth;
- front return stays within the 25 mm lock-zone width;
- shield occupies the same physical master cell as the door/U-catch;
- no slot, sweep, or CAD-004 work has started.

CAD-003 remains blocked at the raw-geometry visual gate.

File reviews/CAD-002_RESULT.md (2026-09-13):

# CAD-002 Design Authority Result

STATUS: APPROVED

## Decision

The corrected CAD-002 evidence at branch `cad/CAD-002` / commit `8dfcdd22e3a1e66fadfbbc6d933be00ca54ff969` satisfies the released static U-catch gate.

## Approved geometry

- Catch plate: **20.0 × 34.5 × 1.5 mm**.
- Two catch mounting holes: **Ø4.2 mm**, **25.0 mm** vertical center-to-center (within the drawing tolerance of ±0.2 mm).
- U-loop rod diameter: **3.0 mm**.
- Two projecting loop legs are arranged **horizontally left-right in plate front view** and share the same Z centerline.
- Leg center-to-center spacing: **14.0 mm**.
- Outside-to-outside rod width: **17.0 mm**.
- Inside clear spacing: **11.0 mm**.
- Loop projection: **26.0 mm nominal** from the plate outer face.
- Catch location preserves the approved **5.0 mm inward edge inset** on the 25 mm hidden return.
- Approved CAD-001 door geometry remains unchanged and healthy, including the existing flat pattern.

## Evidence checks

The machine-readable CAD-002 measurements report all acceptance checks PASS. The catch is parameterized with fully constrained sketches; the approved door revision, volume, topology, bounds, feature count, and flat pattern are unchanged. No shield, lock body, red wall, shim, hinge rod, motion study, or 48-door pattern was added.

## Release

CAD-002 is approved. **CAD-003 is released.**

CAD-003 shall add the blue shield and validate the true moving U-catch sweep only. It must calculate/check the full swept envelope through the operational door rotation and introduce only the minimum shield pass-through / relief required, starting with a **4 mm safety allowance** at the closest moving approach. Do not add the XG-07A lock body, shim, red service wall, hinge rod, or patterned copies in CAD-003.

Stop at the CAD-003 review gate with fresh motion/interference evidence before proceeding to CAD-004.

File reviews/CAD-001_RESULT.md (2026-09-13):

# CAD-001 Design Authority Result

STATUS: APPROVED

## Decision

CAD-001 is approved as the master-door folded baseline.

The review evidence confirms:

- complete formed door envelope: **87.5 × 12.0 × 47.0 mm**;
- fit within the **90 × 50 mm** cell pitch with nominal gaps of **2.5 mm horizontal** and **3.0 mm vertical**;
- derived uninterrupted planar front region: approximately **84.8 × 41.6 mm**;
- 1.2 mm sheet-metal body is valid;
- four required 90-degree bends are healthy and oriented correctly;
- R1.5 mm / K0.42 starting sheet-metal rule is preserved;
- bend relief remains parametric;
- flat pattern generates successfully;
- no U-catch, shield, service wall, lock, shim, hinge rod, or patterned copies were added;
- CAD-002 was not started before this approval.

The abandoned oversized CAD-001R interpretation remains superseded and must not be reused.

## Release

**CAD-002 is RELEASED.**

Codex may proceed with `CAD-002 — Real U-catch on approved door` after synchronizing `main` and creating/switching to branch `cad/CAD-002`.

CAD-002 scope is limited to:

1. preserve the approved CAD-001 sheet-metal door unchanged;
2. model the actual XG-07A U-catch from the supplied dimensions, not a crude bounding block;
3. mount the catch on the 25 mm hidden return with the approved **5 mm inward edge inset**;
4. verify static closed-position geometry and report exact catch position relative to the door and latch-side folds;
5. do **not** add the blue shield, XG-07A lock body, red service wall, shim, hinge rod, or 48-door pattern yet;
6. save the Fusion checkpoint, create CAD-002 evidence and `handoff/CAD-002.json`, push the task branch, then stop for review.

## CAD-002 review emphasis

The catch plate/loop must match the supplied reference dimensions (20 mm × 36.5 mm plate, 1.5 mm plate thickness, approximately 26 mm loop projection) and its mounting orientation must remain compatible with the later full swept-envelope test. Static fit alone is not approval for motion; the motion test belongs to CAD-003.

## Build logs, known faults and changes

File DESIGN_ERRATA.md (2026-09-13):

# Design Errata — KeyBox V2

This file records controlling corrections that have not yet been fully folded back into every older narrative document.

## E-001 — Door size terminology

**Status: CONTROLLING**

For CAD-001 and all later work:

- `87.5 × 47.0 mm` is the **maximum complete formed door envelope** in the cabinet front plane.
- It is **not** the uninterrupted planar center-face size.
- The uninterrupted planar center face is derived from sheet thickness, bend radius, bend tangency and corner-relief geometry.
- The restored CAD-001 baseline measured approximately **84.8 × 41.6 mm** for the uninterrupted planar region; that value is evidence, not a controlling parameter.
- Canonical parameter names are `DOOR_ENVELOPE_W` and `DOOR_ENVELOPE_H`.
- Older references to `DOOR_FACE_W` / `DOOR_FACE_H` are legacy aliases and must not be interpreted as planar-face dimensions.

Reason: forcing the planar center face to 87.5 × 47.0 mm made the formed envelope approximately 90.2 × 52.4 mm and violated the 90 × 50 mm cell pitch.

## E-002 — Blue-shield physical form / U-catch pass-through

**Status: CONTROLLING**

The CAD-003 blue shield is **not** a small four-web rectangular frame around an opening. That representation is rejected.

The intended shield is a formed **L-section** protecting the lock zone:

1. **Side partition** — a 1.2 mm vertical sheet on the constant-X Y-Z plane at nominal `X = 65 mm`, separating the 65 mm tenant key space from the 25 mm lock/shield zone. In the one-row master-cell study it extends rearward from `BLUE_SHIELD_FRONT_SETBACK` toward the compartment rear (`Y ≈ COMP_DEPTH`). In the final cabinet this shielding is vertically continuous for the column where practical.
2. **Front return / front shield face** — at the side partition's leading edge, the sheet turns approximately 90° toward the service-channel side, creating a short constant-Y X-Z face across the lock zone. For CAD-003 use a nominal span equal to `LOCK_ZONE_W = 25 mm` (approximately X = 65..90 mm) as a lightweight reference; final termination will be reconciled with the red service wall in CAD-004.
3. **U-catch passage** — the U-catch must intentionally pass through a **local horizontal slot/notch cut in this front return**, then enter the protected lock zone and engage the XG-07A hook. The slot is derived from the portion of the real moving U-catch envelope that crosses the front return, plus `CATCH_SWEEP_CLEAR = 4.0 mm` minimum clearance to the remaining metal.
4. The slot/notch may be open toward the side-partition/bend edge if the real sweep requires it; do not force a fully enclosed rectangular window if that would collide with the catch. Preserve the maximum practical shield metal around the actual sweep.
5. The long side partition should remain solid except for only the minimum local bend/transition relief proven necessary by the motion study. Do not replace the whole shield with four tiny web bodies around the slot.

`BLUE_SHIELD_FRONT_SETBACK` means the Y position of the L-section's front return / leading bend. It is derived from the door/U-catch sweep while keeping the shield as far forward as practical for anti-tamper protection.

The governing CAD-003 acceptance measurement is clearance between the moving U-catch and the **edges of the slot/notch in the front return and any nearby remaining side-partition/bend metal** throughout 0–90° motion.

Rejected interpretations:

- a full constant-Y wall across the entire 90 mm compartment with a 119 mm projected relief;
- a small freestanding rectangular frame around the opening;
- measuring the catch only against an uncut side-partition plane where it is intended to cross the front return.

Reason: the physical design intent is a continuous protective partition with a short front cap/return over the 25 mm lock zone. The U-catch crosses that front cap through a localized laser-cut slot on its way into the XG-07A hook.

## E-003 — Master-cell occurrence transform / physical placement

**Status: CONTROLLING**

All CAD-003 geometry belonging to the master cell must use the **same occurrence transform as the approved CAD-001 door and CAD-002 U-catch**.

- The approved CAD-001 door and CAD-002 U-catch are both placed at the existing **+550 mm review/master-cell X occurrence transform**.
- Dimensions such as `BLUE_SHIELD_PARTITION_X = 65 mm` are **local master-cell dimensions**, not root/global Fusion-document coordinates.
- The blue shield must therefore be created inside, or transformed with, the same master-cell occurrence frame so that its local X=65 mm plane physically sits beside the approved door and U-catch.
- A shield built at root/global X=65 mm while the door/catch remain at the +550 mm occurrence is invalid even if the shield's local dimensions are numerically correct.
- Before any sweep or clearance work, show one combined isometric view with only the approved door, approved U-catch, reference cell, and blue shield visible. The shield must visibly occupy the intended 25 mm lock zone in the **same cell** as the catch.
- CAD-003 must not claim `READY_FOR_DESIGN_REVIEW` until both the isolated shield view and combined master-cell view confirm correct physical placement.

Reason: the latest L-shield rebuild reports local X=65 mm but the Fusion view shows the new shield geometry physically separated from the approved door/catch, consistent with a root/local occurrence-transform mismatch.

## E-004 — CAD-003 must be anchored to physical master-cell faces

**Status: CONTROLLING**

The latest placement attempt still produces grossly incorrect geometry even after copying the +550 mm occurrence transform. Therefore CAD-003 must stop relying on assumed X/Y/Z orientation or copied transforms as the primary placement method.

Use the **actual visible faces of the approved 90 × 50 × 100 mm master-cell reference** as the construction datum:

- Identify the **front face** physically by the approved door location.
- Identify the **service-side face** physically by the approved U-catch/latch side.
- Identify the **rear face** as the face 100 mm behind the front face.
- Identify the **top and bottom row faces** as the 50 mm row-height boundaries.
- Define the blue-shield side partition as a plane **25.0 mm inward from the actual service-side cell face**. This is physically equivalent to the intended 65/25 mm split, regardless of global axis naming.
- The shield side leg must be bounded by the actual top/bottom row faces and by the actual rear face. No shield material may extend above, below, outside the service-side face, or beyond the rear of the master cell except the nominal 1.2 mm sheet thickness/bend envelope.
- Create the front return from the side-partition leading edge **toward the actual service-side face** for a nominal 25 mm span. Do not infer its direction from a global X sign.
- Use the approved door/U-catch geometry itself to establish which side of the return faces the closing catch.

Before any slot or sweep work, the raw un-notched L-shield must pass a visual/bounding-box gate:

- overall row height ≈ 50 mm maximum;
- width occupied across the lock zone ≈ 25 mm maximum plus bend/sheet envelope;
- depth of the side leg ≤ 100 mm and equals rear-face minus front-setback;
- the entire L-shield sits inside the one physical master cell next to the U-catch.

If any plate appears hundreds of millimetres long, hangs below the cell, rises above the row, or projects outside the 90 × 50 × 100 reference cell, placement/orientation is wrong and CAD-003 must stop before sweep analysis.

Reason: visual review showed a large plate hanging outside the master cell after the transform-only correction, proving that transform equality alone does not guarantee matching local-axis orientation or correct in-context placement.

## E-005 — Both shield legs are vertical; L-shape is seen in TOP view

**Status: CONTROLLING**

The latest raw-shield checkpoint is still wrong because the 25 mm front return was built as a **horizontal shelf/plate** and the side partition rises well beyond one row. This is a plane-orientation error.

For the one-row CAD-003 master-cell reference:

- Local physical axes are conceptual only: **width** across the 90 mm cell, **depth** from door/front to rear across 100 mm, and **height** between the 50 mm row boundaries.
- The **side partition is vertical**: it spans compartment depth and row height. In the canonical coordinate convention it is a constant-X Y-Z plane.
- The **front return is also vertical**: it spans the 25 mm lock-zone width and the same row height. In the canonical coordinate convention it is a constant-Y X-Z plane.
- The 90° bend line between them is therefore **vertical / parallel to the row-height direction**.
- Looking from the **TOP**, the two vertical plates form an `L` footprint.
- Looking from the FRONT, the front return appears as a roughly 25 mm wide × 50 mm high vertical panel, not a horizontal shelf.
- Looking from the SERVICE SIDE, the side partition appears as a depth × 50 mm high vertical panel.
- For this placement gate, both legs must be bounded between the same actual bottom and top row faces. Neither leg may extend above or below the 50 mm row envelope.

To remove any Fusion sheet-metal ambiguity, the next placement checkpoint may use **two simple 1.2 mm solid reference slabs** joined at a vertical corner: one side-partition slab and one front-return slab. Do not attempt a sheet-metal bend, slot, notch, or sweep until these two slabs visually form the correct vertical L inside the cell. The sheet-metal bend can be rebuilt after the placement/orientation gate is approved.

Reason: the user-supplied Fusion checkpoint visibly shows a vertical plate paired with a horizontal shelf and excessive vertical extent. That cannot be the agreed protective L-shield, whose L is a plan/top-view shape made from two vertical faces.

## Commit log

2026-09-12 Initialize KeyBox V2 CAD workspace
2026-09-12 Add KeyBox V2 master CAD specification
2026-09-12 Record current and superseded KeyBox V2 design decisions
2026-09-12 Add Codex CAD execution instructions
2026-09-12 Add staged KeyBox V2 CAD task plan
2026-09-12 Add initial CAD execution log
2026-09-12 CAD-001 master door review gate
    [KeyBox_V2_CAD001_MasterDoor.f3d]
2026-09-12 Add CAD-001 design review: changes required
2026-09-12 Correct CAD-001 review: formed envelope is controlling door size
2026-09-12 Correct CAD-001 envelope requirement and review workflow
2026-09-12 Add agent-to-agent CAD review protocol
2026-09-12 Add controlling CAD-001 door-envelope errata
2026-09-12 Add CAD review pull request template
2026-09-12 Add CAD handoff JSON template
2026-09-13 Approve CAD-001 and release CAD-002
    Merge final CAD-001 evidence, design-authority approval, and CAD-002 release.
    [KeyBox_V2_CAD001_MasterDoor_FINAL.f3d]
2026-09-13 CAD-002 model real U-catch for design review
    [KeyBox_V2_CAD002_UCatch.f3d]
2026-09-13 CAD-002 review: physical loop spacing required
2026-09-13 Resolve CAD-002 physical measurement and issue catch corrections
2026-09-13 Correct CAD-002 U-catch dimensions and orientation
2026-09-13 [CAD-002] Correct catch plate, horizontal loop, and mounting holes for review
    [KeyBox_V2_CAD002_UCatch.f3d]
2026-09-13 Approve corrected CAD-002 and release CAD-003
2026-09-13 Mark CAD-002 approved and release CAD-003
2026-09-13 Align CAD parameters with approved CAD-002 catch geometry
2026-09-13 Release CAD-003 with token-efficient sweep procedure
2026-09-13 CAD-003 review: hold for shield orientation and hinge-axis decision
2026-09-13 CAD-003 hold: correct shield front orientation and freeze hinge axis
2026-09-13 Freeze CAD-003 hinge axis offsets at 5 mm / 5 mm
2026-09-13 Resolve CAD-003 hinge-axis decision and require corrected rerun
2026-09-13 Release corrected CAD-003 rerun with frozen 5 mm hinge axis
2026-09-13 [CAD-003] Correct shield orientation and reject oversized relief
2026-09-13 [CAD-003] Add controlling blue-shield orientation erratum
2026-09-13 [CAD-003] Release corrected side-shield rerun
2026-09-13 [CAD-003] Add nominal blue-shield partition X
2026-09-13 CAD-003: resolve 3.4 mm clearance by setback trim
2026-09-13 Clarify CAD-003 U-catch pass-through intent
2026-09-13 Correct CAD-003 clearance acceptance around pass-through
2026-09-13 [CAD-003] Reject pre-clarification fine-tune and require opening-edge validation
2026-09-13 CAD-003: direct local-opening edge correction after valid 3.40037 mm measurement
2026-09-13 Clarify blue shield as formed L-section with front return slot
2026-09-13 Correct CAD-003 blue shield geometry to formed L-section
2026-09-13 Reject frame shield and release L-section rebuild
2026-09-13 [CAD-003] Freeze master-cell transform rule for shield placement
2026-09-13 [CAD-003] Reject misplaced shield and require transform correction
2026-09-13 CAD-003: anchor blue shield to physical cell faces, not coordinate assumptions
2026-09-13 CAD-003: require physical-face anchored placement checkpoint
2026-09-13 Clarify CAD-003 shield vertical planes and bend axis
2026-09-13 Reject horizontal CAD-003 front return and release vertical L placement gate
